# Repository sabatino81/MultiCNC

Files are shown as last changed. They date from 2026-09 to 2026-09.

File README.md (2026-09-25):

# MultiCNC

MultiCNC is a modular, high-precision desktop CNC platform.

This repository is the engineering source of truth for the project: business case, architecture, BOMs, modules, interfaces, decisions and technical documentation.

## Documentation
Open `index.html` for the navigable engineering dashboard (works from disk, any web root or GitHub Pages subpath).

## Current design principles
- Three bases (Light Core ~18 kg, Standard ~45 kg (mule v2, soglia 42 kg, target 35–37 kg), Pro ~70 kg) sharing work area, pallets, kinematics and the **common mechanical interface** of the ToolDock (ICD v4).
- Two electrical profiles (ICD v4, D026): **Core** on the Light Core (grblHAL, open-loop, manual ToolDock clamp) and **Platform** on Standard and Pro (Mesa + LinuxCNC, closed-loop, automatic ToolDock, data bus).
- The **Platform Pack** is a field upgrade that brings the Light Core to the Platform profile, reusing motors, mechanics and cabling (D026).
- Automatic ToolDock for complete head/module changes on the Platform profile; same master, receiver and pull-stud on every base.
- ATC is separate from ToolDock: ATC changes cutters inside an ATC spindle; ToolDock changes the complete process module.
- Optional enclosure on every base, as an independent skin fixed to the base frame, never to the gantry (D025).
- Modular expansion rather than a fully-loaded base: PCB, aluminium, thermoforming, diode laser, fiber MOPA, knife, dispenser and vision are modular capabilities.
- Specifications marked **TARGET** are engineering goals until validated on hardware. Light Core and Platform Pack BOMs are volume-50 cost targets; Standard and Pro BOMs are single-unit prototype estimates.

## Status
V0.6 — Business chapter, Light Core / Platform Pack, ICD v4, optional enclosure; Standard in development — 25 Sep 2026.

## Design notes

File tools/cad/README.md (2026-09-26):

# CAD parametrico MultiCNC

`parts.py` definisce in CadQuery i componenti commerciali ricorrenti (rotaie e pattini HIWIN, viti SFU con chiocciola, motori NEMA17/23 closed-loop). `build_step.py` li esporta in `cad/step/` insieme a `manifest.json`.

## Digital mule della Standard

- `standard_params.py`: unica fonte di verità geometrica della Standard (corse, componenti, catena di quote, parametri MULE).
- `standard_assembly.py`: costruisce l'assieme in HOME, CENTER, MAX e DOCK (D027), controlla collisioni, giochi e margini di fine corsa, calcola ingombri e masse, verifica D015 con i bracci reali; scrive `cad/standard/standard_mule_<config>.step`, `cad/standard/report.json` e la pagina `base/cad-standard.html` (generata: non modificarla a mano).
- `render_views.py`: viste ortografiche di controllo in `cad/standard/views/` (richiede Pillow).
- `standard_detail.py`: lavorazioni di dettaglio dei pezzi custom (fori di guide, pattini, supporti, chiocciole, motori, interfaccia spalla ICD v4 §5, ToolDock con clamp, porte e connettori) ricavate dalle posizioni reali dei componenti; aggiunge le piastre ponte dei BK/BF Z e compila la viteria. Lo applica `standard_assembly.build()` (`DETAIL = True`); le FEA lo spengono.
- `standard_parts.py`: uno STEP per pezzo custom (coordinate locali) e uno per riga BOM (coordinate HOME) in `cad/standard/parts/`, viste, `manifest.json` (letto dalle BOM) e la pagina `base/cad-parts.html` (generata).
- `standard_accessories.py`: rialzi spalle MC-RS-001 (dettaglio), magazine + trasferitore MC-TD-006 (layout), cabina MC-ENC-001.

```sh
python3 -m venv .venv && .venv/bin/pip install cadquery pillow   # una volta
.venv/bin/python tools/cad/build_step.py                  # rigenera gli STEP dei componenti
.venv/bin/python tools/cad/standard_assembly.py           # assieme, report e pagina
.venv/bin/python tools/cad/render_views.py                # viste
.venv/bin/python tools/cad/standard_parts.py              # STEP e viste dei pezzi di dettaglio, pagina pezzi
python3 tools/bom/build.py                                 # aggiorna i link nelle BOM
```

La mappa riga BOM → file STEP è `OWN` in `tools/bom/cad_sources.py`.

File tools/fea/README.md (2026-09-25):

# FEA a solidi · D031

Pipeline lineare statica per i pezzi del mule Standard: solidi CadQuery dal CAD del mule → mesh Gmsh (tetra
quadratici C3D10, ottimizzati high-order) → `.inp` CalculiX → spostamenti dei punti di riferimento e tensioni nodali.

- `ccx.py`: modulo generico (corpi incollati, corpi rigidi, molle SPRING2 anche rotazionali, molle in direzione
  qualsiasi con equazioni, casi di carico, lettura `.dat` / `.frd`, qualità della mesh).
- `d031.py`: fase 1, modello pilota master ToolDock + testa 5045-style; autotest delle molle, mesh nominale e fine,
  varianti; scrive `fea/d031/pilot.json` e rigenera `base/fea-d031.html` (via `d031_page.py`).

## Requisiti

- Python con CadQuery, numpy, scipy e `gmsh` (`pip install gmsh`; su Linux servono anche `libglu1-mesa`,
  `libxcursor1`, `libxinerama1`, `libxft2`).
- CalculiX `ccx` nel PATH (Ubuntu: `apt install calculix-ccx`, solutore SPOOLES). Un `ccx` compilato con PARDISO
  (per esempio quello di PrePoMax su Windows) è molto più veloce sui modelli grandi.

## Uso

```
python tools/fea/d031.py            # completo: ~40 min con 4 core e SPOOLES
python tools/fea/d031.py --quick    # solo autotest, nominale e mesh fine
python tools/fea/d031.py --resume   # riusa nominale e fine da pilot.json, ricalcola autotest e varianti
python tools/fea/d031_page.py       # solo la pagina dal JSON
```

Fase 2a: `python tools/fea/d031_z.py` (testa + master + slitta Z, quattro topologie master ↔ slitta).
Vista 3D: `python tools/fea/export_results.py` (richiede `trimesh`) scrive le deformate colorate in `fea/d031/glb/` per `base/viewer-3d.html`.

File di lavoro in `build/fea/` (non versionati). Regole D031: carichi su punti di riferimento (mai su un nodo),
spostamento relativo naso ER11 ↔ riferimento, convergenza con dimensioni −30% entro il 5% alla punta, tensione
"hotspot" lontano da vincoli, patch rigide ed elementi scadenti; guide, viti e ToolDock come molle calibrate D028.

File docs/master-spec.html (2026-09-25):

← Dashboard

Source of truth

# Master Specification

I valori marcati TARGET sono obiettivi ingegneristici e non specifiche commerciali finché non saranno validati sul prototipo.

## Piattaforma

Parametro | Specifica
Area XY | TARGET 450 × 350 mm
Z CNC | TARGET 120–140 mm
Line-up | Tre basi: Light / Standard / Pro (D007); in sviluppo la Standard
Massa meccanica | TARGET ~18 / ~32 / ~70 kg, quadro elettrico esterno
Clearance | Rialzi manuali (Light, Standard); TARGET 0–150 mm Gantry Lift motorizzato (Pro)
Load case | D014: forze, momenti, accelerazioni, crash e rigidezza alla punta per base
Interfacce comuni | Congelate in ICD v4 (D012): ToolDock, connettore, Module ID, pallet, rialzi, quadro
Carico ToolDock | TARGET 2 / 4 / 7 kg testa completa
Motion | Ponte fisso + tavola mobile Y con vite centrale (D006); guide lineari + viti a ricircolo; closed-loop su Standard e Pro; open-loop sulla Light Core, closed-loop con Platform Pack (D024)
Ingombro Y | TARGET ~750–800 mm, corsa Y + lunghezza tavola, da confermare in CAD
Controller | Standard e Pro: Mesa 7i96S + LinuxCNC + espansione I/O (ICD v4), modello scheda da confermare. Light Core: grblHAL 32 bit con driver integrati; Mesa + LinuxCNC con il Platform Pack (D024, D026)
Altezza pezzo | Non coincide con la corsa Z (140 mm): sotto la trave ci sono 150 mm sopra la tavola, meno pallet e fixture (con pallet 15 mm ~135 mm), +75 mm con i rialzi (D007, D028). Nelle specifiche si dichiarano separatamente
Cabina | Opzionale su tutte le basi (D025): telaio indipendente agganciato al basamento, mai al ponte; porta con interlock, LED, aspirazione Ø100, vasca trucioli; i kit laser richiedono una variante laser-ready o una schermatura propria, qualificate per il modulo specifico (lunghezza d'onda, protezione ottica, interlock, fughe)

## Regole architetturali

Ogni base deve funzionare autonomamente come router CNC; Interfaccia meccanica ToolDock, pallet e cinematica sono comuni alle tre; elettronica e ToolDock automatico sono comuni a Standard e Pro, la Light Core li riceve con il Platform Pack (D024). Thermoforming, PCB specialistico, Aluminium Pro, diode, fiber, knife, dispenser e vision sono moduli.

## Precisione

Accuratezza e ripetibilità restano target finché non definiamo metrologia, condizioni termiche e protocollo di test sul prototipo.

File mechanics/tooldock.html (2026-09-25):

← Dashboard

Universal interface

# Automatic ToolDock

Interfaccia universale tra carrello Z e moduli di processo, progettata per deposito e prelievo automatico della testa.

## Requisiti congelati

- Un solo master ToolDock sulla macchina.
- Ogni testa possiede una receiver plate compatibile.
- Cambio automatico completo: deposito, sgancio, prelievo, aggancio e identificazione.
- Connessioni per potenza, segnali/dati e, dove richiesto, aria o fluido.
- Offset specifici del modulo memorizzati dal controllo.
- Rack raggiungibile cinematicamente dalla macchina.

## ToolDock vs ATC

ToolDock cambia una tecnologia completa. Un modulo spindle ISO20 ATC può successivamente cambiare le proprie frese usando un rack ATC separato.

Congelato in ICD v4 (D012): accoppiamento a 3 sfere, clamp a molla con sgancio passivo dal dock, classi di carico 2/4/7 kg e pin-out del connettore. Restano TARGET la ripetibilità (≤ 10 µm) e il tempo di cambio. Apri la ICD → · Validazione meccanica D016 →

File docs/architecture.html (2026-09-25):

← Dashboard

System architecture

# One machine. Multiple processes.

## XYZ Precision Motion

È la cinematica di lavorazione: X e Z sul ponte fisso, Y come tavola mobile con vite centrale (D006). Deve restare indipendente dal meccanismo di regolazione altezza gantry.

## Clearance · Gantry Lift G

Light e Standard: rialzi manuali spinati. Pro: due punti di sollevamento sincronizzati. Serve per cambiare clearance; durante il taglio il carico si chiude su riferimenti/blocchi meccanici, non sul motore di lift.

## Automatic ToolDock

Cambia l'intero modulo di processo: spindle base, micro-spindle PCB, laser, knife, dispenser, vision/probe e futuri moduli. Automatico su Standard e Pro; sulla Light Core la stessa interfaccia è a bloccaggio manuale finché non monta il Platform Pack (D024).

## ATC ≠ ToolDock

Un futuro spindle ISO20 ATC cambia le proprie frese. ToolDock cambia invece l'intera testa ISO20 con un'altra tecnologia.

## Interchangeable Pallets

Piano CNC, vacuum PCB, thermoforming plenum, laser honeycomb e fixture speciali condividono riferimenti geometrici definiti.

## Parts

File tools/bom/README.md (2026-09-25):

# BOM generator

Le tabelle delle quattro BOM (tre basi e Platform Pack) sono generate da dati Python, non scritte a mano. Standard e Pro: stime di prototipo a pezzo singolo. Light Core e Platform Pack: costi TARGET a lotto da 50 (D023).

| Base | Dati | Pagina |
|---|---|---|
| Light Core | `data_light.py` | `bom/base-light.html` (prezzi TARGET a lotto da 50, D024) |
| Standard | `data_standard.py` | `bom/base.html` |
| Pro | `data_pro.py` | `bom/base-pro.html` |
| Platform Pack | `data_platform.py` | `bom/platform-pack.html` (upgrade Light Core, prezzi TARGET a lotto da 50, D026) |

## Uso

Dalla radice del repository:

```sh
python3 tools/bom/build.py          # riscrive righe, KPI e totali nelle tre pagine
python3 tools/bom/build.py --check  # verifica soltanto; exit 1 se una pagina non è allineata
```

Lo script stampa per ogni base righe, costo prototipo, massa sulla macchina, massa esterna e massa per gruppo.

## Formato di una riga

```python
("MC-TD-001", "ToolDock", "Master kinematic plate", "1", 1,
 "Custom 3-point kinematic interface", "Montata sul carrello Z",
 150, 0.6, "M", "critical", "CRITICAL DESIGN")
```

id · gruppo · componente · quantità (etichetta) · quantità (numero) · candidate · specifica · €/cad · kg/cad · dove · classe stato · stato

- **dove**: `M` sulla macchina, `C` nel quadro o in unità esterne, `A` accessorio (elencato ma escluso dai totali).
- **classe stato**: `design`, `source`, `validate`, `critical`, `ok` (colore della pillola).
- **Codici**: `MC-` parti comuni alle tre basi, `ML-` solo Light, `MP-` solo Pro; le parti della sola Standard usano ancora `MC-`.

## Colonna CAD / STEP

`cad_sources.py` decide cosa mostrare per ogni id:

- `BY_ID` → link alla pagina ufficiale del produttore (`VENDOR`), verificato a mano;
- id di parti custom (`CUSTOM`) → "MultiCNC CAD · in arrivo";
- tutto il resto → "Generico · STEP dal fornitore scelto".

I file dei produttori non vanno copiati nel repository: le loro condizioni d'uso di solito ne vietano la ripubblicazione.

## Cosa non fa

Aggiorna solo tabella, i 4 KPI e la riga "Stima ingegneristica attuale". Testi, callout, target e pannelli restano nell'HTML: se un cambio di dati li rende falsi (per esempio una massa citata nel callout), vanno corretti a mano insieme alle altre pagine che citano quei numeri.

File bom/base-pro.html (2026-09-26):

ID | Gruppo | Componente | Q.tà | Candidate / Part | Specifica tecnica | €/cad target | Subtotale | Massa kg | Stato | CAD / STEP
A · Struttura e riferimenti
MP-BAS-001 | Structure | Basamento lavorato | 1 | Scala in tubi Al 80×60 sp. 4, senza fondo, saldata e lavorata | Longheroni, traversa BF, traversa BK Y e traversa di coda; 4 sbalzi 80×60 sotto le flange ICD §5 dei montanti del lift, niente traversa anteriore (CAD v2, D037) | €250 | €250 | 8.6 macchina | CAD v1 | STEP pezzo ↓CAD di dettaglio
MP-GAN-001 | Structure | Trave gantry | 1 | Scatolato Al 100×170, faccia guide 8, pareti 4, testate 5 | Ponte fisso (D006), canale vite X, staffe del Gantry Lift sul retro (CAD v2, D037) | €160 | €160 | 5.8 macchina | CAD v1 | STEP pezzo ↓CAD di dettaglio
MP-GAN-002 | Structure | Spalle gantry | 2 | Custom Al 12 mm finestrato + traversa superiore 12 × 30 | Montanti del Gantry Lift dietro la trave, 4 finestre ai lati della guida, flangia ICD §5 12 mm scaricata; portano guide, viti, cinghia e motore G (CAD v2, D037) | €60 | €120 | 4.6 macchina | CAD v1 | STEP pezzo ↓CAD di dettaglio
MP-Z-001 | Structure | Piastra asse Z | 1 | Custom Al 5083 12 mm, ali 10 | Guide Z + ToolDock master (CAD v2, D037) | €80 | €80 | 1.1 macchina | CAD v1 | STEP pezzo ↓CAD di dettaglio
MP-XC-001 | Structure | Carrello X | 1 | Al 12 mm, piastra + torre + ali 10 | Porta pattini X, guide Z, vite, supporti e motore Z (CAD v2, D037) | €120 | €120 | 4.4 macchina | CAD v1 | STEP pezzo ↓CAD di dettaglio
MP-BRK-001 | Structure | Staffe chiocciole, motori e supporti | 1 set | Custom Al, 7 pezzi | Staffe chiocciola X e Y, piastrina chiocciola Z, staffa motore Z, spessori BK/BF X, piastre ponte BK/BF Z (CAD di dettaglio v1, D035) | €45 | €45 | 0.9 macchina | CAD v1 | STEP pezzo ↓CAD di dettaglio
MP-TBL-001 | Workholding | Tavola Y / tooling plate | 1 | Al tooling plate 12 mm | Tavola mobile Y (D006), 450×350 utile; spessore pieno, inserti M6 per usura (D018) | €120 | €120 | 5.0 macchina | CAD v1 | STEP pezzo ↓CAD di dettaglio
MP-HW-001 | Structure | Fasteners + dowel pins | 1 set | ISO high-strength | Viteria, spine rettificate, rondelle, inserti | €50 | €50 | 1.0 macchina | TO SOURCE | GenericoSTEP dal fornitore scelto
MC-TBL-002 | Workholding | Inserti M6 + boccole R1/R2 | 1 set | 63 inserti filettati M6 in acciaio + 2 boccole Ø8 H7 | Filetto utile 9 mm nei boss; R1 (50, 50) tonda, R2 (400, 50) asola (ICD v4, D018) | €25 | €25 | 0.1 macchina | TO SOURCE | GenericoSTEP dal fornitore scelto
B · Cinematica XYZ
MP-LIN-201 | XY | Guide lineari HGR20 | 4 rails | HIWIN HGR20 class | 2 rail Y nel basamento + 2 rail X sulla trave, 650 mm (D019) | €60 | €240 | 5.8 macchina | TO SOURCE | STEP MultiCNC ↓modello a quote realiHIWIN CAD ↗ (https://www.hiwinsupport.com/cad_download/linear_guideway.aspx)account gratuito
MP-LIN-202 | XY | Pattini HGH20CA | 8 | HIWIN HGH20CA class | 2 pattini per rail; preload TBC | €20 | €160 | 2.4 macchina | TO SOURCE | STEP MultiCNC ↓modello a quote realiHIWIN CAD ↗ (https://www.hiwinsupport.com/cad_download/linear_guideway.aspx)account gratuito
MP-LIN-151 | Z | Guide lineari HGR15 | 2 rails | HIWIN HGR15 class | 320 mm (D019), corsa Z 120–140 mm | €32 | €64 | 0.9 macchina | TO SOURCE | STEP MultiCNC ↓modello a quote realiHIWIN CAD ↗ (https://www.hiwinsupport.com/cad_download/linear_guideway.aspx)account gratuito
MP-LIN-152 | Z | Pattini HGH15CA | 4 | HIWIN HGH15CA class | 4 pattini complessivi | €15 | €60 | 0.7 macchina | TO SOURCE | STEP MultiCNC ↓modello a quote realiHIWIN CAD ↗ (https://www.hiwinsupport.com/cad_download/linear_guideway.aspx)account gratuito
MP-BS-1605X | X | Ball screw X | 1 | SFU1605 C7 precaricata | 590 mm totali (D019); precarico/errore passo da qualificare. Massa dal CAD: vite piena Ø16 + chiocciola (limite superiore) | €55 | €55 | 1.1 macchina | TO VALIDATE | STEP MultiCNC ↓modello a quote reali
MP-BS-1605Y | Y | Ball screw Y | 1 | SFU1605 C7 precaricata | Vite singola centrale sotto la tavola (D006), 490 mm totali (D019). Massa dal CAD (limite superiore) | €55 | €55 | 1.0 macchina | TO VALIDATE | STEP MultiCNC ↓modello a quote reali
MP-BS-1204Z | Z | Ball screw Z | 1 | SFU1204 C7 | 260 mm totali (D019). Massa dal CAD (limite superiore) | €45 | €45 | 0.3 macchina | TO VALIDATE | STEP MultiCNC ↓modello a quote reali
MP-BKBF-001 | XYZ | Supporti BK/BF precision | 3 set | BK/BF matched class | Supporti cuscinetto per le tre viti | €25 | €75 | 1.8 macchina | TO SOURCE | GenericoSTEP dal fornitore scelto
MP-CPL-001 | XYZ | Giunti motore-vite | 3 | Zero/low backlash bellows class | Da evitare giunti elicoidali economici | €15 | €45 | 0.4 macchina | TO SOURCE | GenericoSTEP dal fornitore scelto
MP-MOT-001 | XYZ | Motori NEMA23 closed-loop 3 Nm | 3 | StepperOnline 3 Nm class | Motore + encoder sulla macchina | €43 | €129 | 4.5 macchina | CANDIDATE | STEP MultiCNC ↓modello a quote realiStepperOnline ↗ (https://www.omc-stepperonline.com/nema-23-closed-loop-stepper-motor-3-0nm-424oz-in-encoder-1000ppr-4000cpr-23hs45-4204d-e1000)23HS45-4204D-E1000
MP-DRV-001 | XYZ | Driver closed-loop | 3 | CL57T class, ~48 V | Nel quadro esterno | €22 | €66 | 1.0 esterno | CANDIDATE | StepperOnline ↗ (https://www.omc-stepperonline.com/closed-loop-stepper-kit)kit closed-loop
C · Gantry Lift motorizzato (solo Pro)
MP-GL-LIN1 | Gantry Lift | Guide verticali HGR15 | 2 rails | HIWIN HGR15 class | Una guida per montante, 350 mm (verificata D019) | €30 | €60 | 1.0 macchina | TO DESIGN | STEP MultiCNC ↓modello a quote realiHIWIN CAD ↗ (https://www.hiwinsupport.com/cad_download/linear_guideway.aspx)account gratuito
MP-GL-LIN2 | Gantry Lift | Pattini HGH15 | 4 | HIWIN HGH15 class | 2 pattini per lato | €15 | €60 | 0.7 macchina | TO DESIGN | STEP MultiCNC ↓modello a quote realiHIWIN CAD ↗ (https://www.hiwinsupport.com/cad_download/linear_guideway.aspx)account gratuito
MP-GL-BS | Gantry Lift | Viti sollevamento | 2 | SFU1605 class | Sollevamento sincronizzato, non asse di taglio; 350 mm totali. Massa dal CAD (limite superiore) | €40 | €80 | 1.5 macchina | TO DESIGN | STEP MultiCNC ↓modello a quote reali
MP-GL-BK | Gantry Lift | Supporti BK/BF lift | 2 set | BK/BF12 class | Supporto viti lift | €20 | €40 | 1.0 macchina | TO SOURCE | GenericoSTEP dal fornitore scelto
MP-GL-MOT | Gantry Lift | Motore G | 1 | NEMA23 closed-loop class | Asse di setup, non richiede precisione metrologica | €43 | €43 | 1.5 macchina | CANDIDATE | STEP MultiCNC ↓modello a quote realiStepperOnline ↗ (https://www.omc-stepperonline.com/nema-23-closed-loop-stepper-motor)NEMA23 closed-loop
MP-GL-DRV | Gantry Lift | Driver G | 1 | CL57T class | Nel quadro esterno | €22 | €22 | 0.3 esterno | CANDIDATE | StepperOnline ↗ (https://www.omc-stepperonline.com/closed-loop-stepper-kit)kit closed-loop
MP-GL-SYNC | Gantry Lift | Sincronizzazione | 1 set | HTD belt + pulleys + shaft | Sincronizza le due viti verticali; massa dal CAD (pulegge piene, cinghia, giunto) | €50 | €50 | 0.9 macchina | TO DESIGN | GenericoSTEP dal fornitore scelto
MP-GL-LOCK | Gantry Lift | Locking + references | 1 set | Custom clamp / wedge / dowel | Scarica il lift durante la lavorazione; staffe trave a C (D037) | €100 | €100 | 2.0 macchina | CRITICAL DESIGN | STEP pezzo ↓CAD di dettaglio
D · Spindle base
MP-SP-001 | Spindle | Spindle 1.5 kW ER16 | 1 | Water-cooled 80 mm class | ~24k rpm; runout da bench-test; testa entro il carico ToolDock di 7 kg | €160 | €160 | 4.5 macchina | TO QUALIFY | GenericoSTEP dal fornitore scelto
MP-SP-002 | Spindle | VFD vector | 1 | 1.5 kW class | RS485/analog; nel quadro esterno | €120 | €120 | 1.5 esterno | TO SOURCE | GenericoSTEP dal fornitore scelto
MC-SP-006 | Spindle | Contattore uscita spindle | 1 | Contattore AC-3 con contatto ausiliario | Apre P1–P3 a valle di VFD/driver prima dello sgancio della testa (ICD v4, D020) | €25 | €25 | 0.2 esterno | TO DESIGN | GenericoSTEP dal fornitore scelto
MP-SP-003 | Spindle | Spindle mount | 1 | Custom machined clamp | Receiver-compatible con ToolDock | €40 | €40 | 1.1 macchina | CAD v1 | STEP pezzo ↓CAD di dettaglio
MP-SP-004 | Cooling | Cooling loop | 1 | Pump + radiator + reservoir | Unità esterna a circuito chiuso | €60 | €60 | 2.5 esterno | TO SOURCE | GenericoSTEP dal fornitore scelto
MP-SP-005 | Tooling | ER16 collet starter set | 1 | Precision collets class | Starter tooling only | €30 | €30 | 0.3 macchina | TO SOURCE | GenericoSTEP dal fornitore scelto
E · ToolDock (identico sulle tre basi)
MC-TD-001 | ToolDock | Master kinematic plate | 1 | Stessa parte della Standard | Montata sul carrello Z | €150 | €150 | 1.0 macchina | CRITICAL DESIGN | STEP pezzo ↓CAD di dettaglio
MC-TD-002 | ToolDock | Base spindle receiver | 1 | Receiver ICD comune, 110 × 110 per il mount Ø80 | Stesso accoppiamento, pull-stud e porte della Standard; più largo (110, limite ICD) per le viti del mount dello spindle Ø80 (CAD v1) | €80 | €80 | 0.5 macchina | CAD v1 | STEP pezzo ↓CAD di dettaglio
MC-TD-003 | ToolDock | Automatic clamp | 1 | Pull-stud comune (ICD v4) | Pacco molle ≥ 3,8 kN (classe P), sgancio passivo con camma 3:1 (D016) | €100 | €100 | 0.4 macchina | CRITICAL DESIGN | STEP pezzo ↓CAD di dettaglio
MC-TD-004 | ToolDock | Hybrid connector set | 1 | Stessa parte della Standard | Power + signal + ID | €120 | €120 | 0.3 macchina | CRITICAL DESIGN | GenericoSTEP dal fornitore scelto
MC-TD-005 | ToolDock | Module ID | 1 | Stessa parte della Standard | Identificazione automatica | €30 | €30 | 0.0 macchina | TO DESIGN | GenericoSTEP dal fornitore scelto
MC-TD-007 | ToolDock | Connettore dati | 1 | Blind-mate a contatti a molla, schermato | Ethernet 1000BASE-T (4 coppie) + CAN FD + encoder RS-422 differenziale (ICD v4, D020) | €60 | €60 | 0.1 macchina | TO SOURCE | GenericoSTEP dal fornitore scelto
F · Controllo (quadro esterno)
MC-CTRL-001 | Control | Motion controller | 1 | Mesa 7i96S | Comune alle tre basi; I/O da verificare con il lift | €160 | €160 | 0.2 esterno | I/O REVIEW | Mesa ↗ (http://www.mesanet.com/)nessuno STEP ufficiale
MC-CTRL-003 | Control | Espansione I/O | 1 | Scheda Mesa su porta di espansione 7i96S (modello da confermare) | ≥ +16 ingressi / +8 uscite 24 V: home, probe, setter, conferme ToolDock, sensori testa, interlock (ICD v4) | €90 | €90 | 0.2 esterno | I/O REVIEW | GenericoSTEP dal fornitore scelto
MC-CTRL-004 | Control | Interfaccia CAN FD | 1 | Adattatore USB–CAN FD | Bus moduli ToolDock (ICD v4, D020) | €40 | €40 | 0.1 esterno | TO SOURCE | GenericoSTEP dal fornitore scelto
MC-CTRL-002 | Compute | Fanless mini PC | 1 | x86 LinuxCNC, 2 porte Ethernet | Porta 1 dedicata alla Mesa, porta 2 per il bus dati ToolDock (D017) | €150 | €150 | 0.8 esterno | TO SOURCE | GenericoSTEP dal fornitore scelto
MP-PWR-001 | Power | 48 V PSU | 1 | Mean Well LRS-600-48 | Motion supply, 4 assi | €70 | €70 | 1.3 esterno | TO SOURCE | Mean Well ↗ (https://www.meanwell.com/webapp/product/search.aspx?prod=LRS-600)LRS-600
MC-PWR-002 | Power | 24 V PSU | 1 | Mean Well HDR-100-24 | ~92 W (24 V × 3,83 A): I/O, sensori, logica ToolDock; 40 W garantiti ai moduli (ICD v4, D022) | €45 | €45 | 0.3 esterno | TO SOURCE | Mean Well ↗ (https://www.meanwell.com/webapp/product/search.aspx?prod=HDR-100)HDR-100
MP-PWR-003 | Power | 48 V MODULE AUX | 1 | Mean Well LRS-350-48 | Linea 48 V dedicata ai moduli ToolDock, separata dal motion (ICD v4, D020) | €60 | €60 | 0.8 esterno | TO SOURCE | Mean Well ↗ (https://www.meanwell.com/webapp/product/search.aspx?prod=LRS-350)LRS-350
MC-SAFE-001 | Safety | E-stop + contactor chain | 1 set | Industrial safety hardware | Arresto energia motion/process | €80 | €80 | 0.5 esterno | TO DESIGN | GenericoSTEP dal fornitore scelto
MP-IO-001 | I/O | Relays / terminal blocks / protection | 1 set | DIN rail industrial | Fusibili, interruttori, relè, morsetti | €90 | €90 | 0.8 esterno | TO SOURCE | GenericoSTEP dal fornitore scelto
MP-EL-BOX | Electrical | Quadro elettrico esterno | 1 | DIN cabinet | Controller, PSU, driver, VFD separato | €80 | €80 | 3.0 esterno | TO DESIGN | GenericoSTEP dal fornitore scelto
G · Cablaggio, sensori e metrologia
MP-CAB-001 | Electrical | Cavi schermati macchina–quadro | 1 set | Motion + spindle + I/O | EMC-aware routing, 4 assi | €100 | €100 | 1.2 macchina | TO SOURCE | GenericoSTEP dal fornitore scelto
MP-CHAIN-001 | Mechanical | Drag chains | 1 set | Low-profile cable chain | X/Z sul ponte + escursione lift | €50 | €50 | 0.6 macchina | TO SOURCE | GenericoSTEP dal fornitore scelto
MC-SNS-001 | Sensing | Home/limit sensors | 6 | Inductive industrial class | XYZ + gantry lift reference | €8 | €48 | 0.3 macchina | TO SOURCE | GenericoSTEP dal fornitore scelto
MC-PROBE-001 | Metrology | XYZ touch probe | 1 | Wired probe class | Work offset / edge finding | €45 | €45 | 0.2 macchina | TO QUALIFY | GenericoSTEP dal fornitore scelto
MC-TOOL-001 | Metrology | Tool length setter | 1 | Wired setter class | Tool length reference | €55 | €55 | 0.3 macchina | TO QUALIFY | GenericoSTEP dal fornitore scelto
H · Accessori (non inclusi nei totali)
MP-ENC-001 | Enclosure | Cabina opzionale Pro | 1 | Telaio indipendente rinforzato + pannelli PC 5 mm + porta con interlock | Più alta per il Gantry Lift e lo spindle ad acqua; agganciata al basamento, mai al ponte; LED, aspirazione Ø100, vasca trucioli e MQL; prezzo TARGET a lotto 50 (D025) | €380 | €380 | 18.0 accessorio | TO DESIGN | STEP pezzo ↓CAD di dettaglio
MC-TD-006 | ToolDock | Magazine indicizzato | 1 | 2–4 posti, indicizzazione motorizzata | Sul ponte; presenta la testa in un'unica posizione di docking; forcelle con sensore di cattura, camma di sgancio 3:1 (D016, D021) | €200 | €200 | 2.0 accessorio | TO DESIGN | STEP pezzo ↓CAD di dettaglio
I · Totali provvisori
Stima ingegneristica attuale (target cost, non RFQ) |  |  |  |  |  |  | €4,557 | 69.6 + 13.6 | PROVISIONAL
Target Base Pro |  |  |  |  |  |  | da definire | ~70 | ACCEPTED

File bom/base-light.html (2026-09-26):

ID | Gruppo | Componente | Q.tà | Candidate / Part | Specifica tecnica | €/cad target | Subtotale | Massa kg | Stato | CAD / STEP
A · Struttura e riferimenti
ML-BAS-001 | Structure | Telaio basamento | 1 | Tubi Al 40×40×1,5 saldati a scala, pad e sedi lavorati in lotto | Due longheroni, traversa BF, traversa di coda 40×80 (BK Y + motore Y), 4 sbalzi 40×40 sotto le flange ICD §5 delle spalle; niente traversa anteriore (CAD v2, D036) | €80 | €80 | 1.8 macchina | CAD v1 | STEP pezzo ↓CAD di dettaglio
ML-GAN-001 | Structure | Trave gantry | 1 | Tubo Al 40×80, faccia guide 4 mm, pareti 2 mm, lavorato in lotto | Ponte fisso (D006), senza canale: guide X MGN12 a 52 mm sulla faccia, vite X e BK10/BF10 sul cielo; blocchetti d'angolo per le M6 delle spalle (CAD v2, D036) | €35 | €35 | 1.2 macchina | CAD v1 | STEP pezzo ↓CAD di dettaglio
ML-GAN-002 | Structure | Spalle gantry | 2 | Al 5083 4 mm + flangia 10 mm scaricata, taglio + lavorazione in lotto | Ai lati della trave, flangia ICD §5 spinata al telaio (pattern invariato, rialzi +50, D007); motore X sulla spalla destra all'altezza della vite (CAD v2, D036) | €15 | €30 | 0.7 macchina | CAD v1 | STEP pezzo ↓CAD di dettaglio
ML-Z-001 | Structure | Piastra asse Z | 1 | Al 5083 6 mm con ali 5 mm | Guide Z + master ToolDock (CAD v2, D036) | €18 | €18 | 0.3 macchina | CAD v1 | STEP pezzo ↓CAD di dettaglio
ML-XC-001 | Structure | Carrello X | 1 | Al 6 mm, piastra + torre, senza ali | Porta pattini X, guide Z a 90 mm, vite, BK Z e motore Z; sopra i pattini X si stringe a 110 mm (CAD v2, D036) | €22 | €22 | 0.5 macchina | CAD v1 | STEP pezzo ↓CAD di dettaglio
ML-BRK-001 | Structure | Staffe chiocciole, motori e supporti | 1 set | Custom Al, 6 pezzi | Staffa chiocciola X sopra la trave, staffa chiocciola Y, piastrina chiocciola Z, staffa motore Z, spessori BK/BF X sul cielo trave, piastra ponte BK Z (CAD v2, D036) | €8 | €8 | 0.5 macchina | CAD v1 | STEP pezzo ↓CAD di dettaglio
ML-TBL-001 | Workholding | Tavola Y / tooling plate | 1 | Al 9 mm, tasche e boss pieni | Tavola mobile Y (D006), 450×350 utile; pelle 4 mm, boss Ø16 × 9 mm attorno ai fori M6 e ai riferimenti (D018): stessi pallet delle altre basi | €60 | €60 | 2.2 macchina | CAD v1 | STEP pezzo ↓CAD di dettaglio
ML-HW-001 | Structure | Fasteners + dowel pins | 1 set | ISO | Viteria, spine, inserti | €15 | €15 | 0.4 macchina | TO SOURCE | GenericoSTEP dal fornitore scelto
MC-TBL-002 | Workholding | Inserti M6 + boccole R1/R2 | 1 set | 63 inserti filettati M6 in acciaio + 2 boccole Ø8 H7 | Filetto utile 9 mm nei boss; R1 (50, 50) tonda, R2 (400, 50) asola (ICD v4, D018) | €14 | €14 | 0.1 macchina | TO SOURCE | GenericoSTEP dal fornitore scelto
B · Cinematica XYZ
ML-LIN-151 | XY | Guide lineari MGN12 | 4 rails | MGN12, HIWIN o equivalente qualificato | 2 rail X 620 mm + 2 rail Y 580 mm (passo pattini Y 160, Light a piastre D036) | €18 | €72 | 1.6 macchina | TO SOURCE | STEP MultiCNC ↓modello a quote realiHIWIN CAD ↗ (https://www.hiwinsupport.com/cad_download/linear_guideway.aspx)account gratuito
ML-LIN-152 | XY | Pattini MGN12H | 8 | MGN12H, HIWIN o equivalente qualificato | 2 pattini per rail, versione lunga, precarico Z1: equivalente accettato solo con rigidezza ≥ HIWIN (175 N/µm, D022) | €5 | €40 | 0.4 macchina | TO SOURCE | STEP MultiCNC ↓modello a quote realiHIWIN CAD ↗ (https://www.hiwinsupport.com/cad_download/linear_guideway.aspx)account gratuito
ML-LIN-153 | Z | Guide lineari MGN12 | 2 rails | MGN12, HIWIN o equivalente qualificato | 280 mm (D019) | €9 | €18 | 0.4 macchina | TO SOURCE | STEP MultiCNC ↓modello a quote realiHIWIN CAD ↗ (https://www.hiwinsupport.com/cad_download/linear_guideway.aspx)account gratuito
ML-LIN-154 | Z | Pattini MGN12H | 4 | MGN12H, HIWIN o equivalente qualificato | 4 pattini complessivi | €5 | €20 | 0.2 macchina | TO SOURCE | STEP MultiCNC ↓modello a quote realiHIWIN CAD ↗ (https://www.hiwinsupport.com/cad_download/linear_guideway.aspx)account gratuito
ML-BS-1204X | X | Ball screw X | 1 | SFU1204 C7 rullata | 570 mm totali, estremità BK/BF comprese (D019); sopra la trave (D036). Massa dal CAD: vite piena Ø12 + chiocciola (limite superiore) | €22 | €22 | 0.6 macchina | TO VALIDATE | STEP MultiCNC ↓modello a quote reali
ML-BS-1204Y | Y | Ball screw Y | 1 | SFU1204 C7 rullata | Vite singola centrale sotto la tavola (D006), 480 mm totali (CAD v1: 8 mm fra staffa e BK a fine corsa). Massa dal CAD (limite superiore) | €22 | €22 | 0.5 macchina | TO VALIDATE | STEP MultiCNC ↓modello a quote reali
ML-BS-1204Z | Z | Ball screw Z | 1 | SFU1204 C7 rullata | 260 mm totali (D019), fissa-libera: solo BK10 in alto (D036). Massa dal CAD (limite superiore) | €22 | €22 | 0.3 macchina | TO VALIDATE | STEP MultiCNC ↓modello a quote reali
ML-BKBF-001 | XYZ | Supporti BK10/BF10 | 2 set + 1 BK10 | BK/BF class | Set BK10/BF10 per X (sul cielo della trave) e Y; solo BK10 per la Z fissa-libera (D036) | €23 | €23 | 0.9 macchina | TO SOURCE | GenericoSTEP dal fornitore scelto
ML-CPL-001 | XYZ | Giunti motore-vite | 3 | Low backlash bellows class | Taglia NEMA17 | €5 | €15 | 0.2 macchina | TO SOURCE | GenericoSTEP dal fornitore scelto
ML-MOT-002 | XYZ | Motori NEMA17 encoder-ready | 3 | NEMA17 ~0,6 Nm, doppio albero | Open-loop sulla Core; il Platform Pack aggiunge un encoder a innesto sul secondo albero, i motori restano (D026). Crash load D014 invariato | €14 | €42 | 1.2 macchina | CANDIDATE | GenericoSTEP dal fornitore scelto
C · Spindle base
ML-SP-001 | Spindle | Spindle BLDC 300–500 W | 1 | ER11, air-cooled | Testa completa entro il carico ToolDock di 2 kg | €60 | €60 | 1.0 macchina | TO QUALIFY | GenericoSTEP dal fornitore scelto
ML-SP-002 | Spindle | Driver BLDC + alimentatore | 1 | 0,5 kW class, alimentatore dedicato | Nel quadro; enable dal controller, tolto dal consenso cambio testa | €45 | €45 | 0.8 quadro | TO SOURCE | GenericoSTEP dal fornitore scelto
ML-SP-003 | Spindle | Spindle mount | 1 | Custom machined clamp | Receiver-compatible con ToolDock | €12 | €12 | 0.2 macchina | CAD v1 | STEP pezzo ↓CAD di dettaglio
ML-SP-005 | Tooling | ER11 collet starter set | 1 | 2 pinze (3,175 · 6 mm) | Starter tooling only | €3 | €3 | 0.1 macchina | TO SOURCE | GenericoSTEP dal fornitore scelto
D · ToolDock manuale (interfaccia ICD comune)
ML-TD-001 | ToolDock | Master kinematic plate | 1 | Stesso accoppiamento a 3 sfere e pull-stud delle altre basi | Montata sul carrello Z; sedi già lavorate per clamp automatico, connettore ibrido e connettore dati del Platform Pack | €60 | €60 | 0.4 macchina | CRITICAL DESIGN | STEP pezzo ↓CAD di dettaglio
ML-TD-002 | ToolDock | Base spindle receiver | 1 | Receiver ICD comune | Stessa receiver delle altre basi: le teste restano intercambiabili | €30 | €30 | 0.3 macchina | CAD v1 | STEP pezzo ↓CAD di dettaglio
ML-TD-003 | ToolDock | Clamp manuale | 1 | Leva a camma sul pull-stud comune | Preload ≥ 0,5 kN come la classe L (D016); sostituito dal clamp automatico nel Platform Pack, che si monta nelle stesse sedi | €35 | €35 | 0.2 macchina | CRITICAL DESIGN | STEP pezzo ↓CAD di dettaglio
ML-TD-004 | ToolDock | Connettore modulo manuale | 1 | Circolare industriale 12 poli | Spindle, 48 V modulo, I/O e ID; si innesta a mano, solo con consenso cambio testa attivo | €15 | €15 | 0.1 macchina | TO SOURCE | GenericoSTEP dal fornitore scelto
MC-TD-005 | ToolDock | Module ID | 1 | 1-Wire comune | Stesso ID delle altre basi: il controller rifiuta le teste non Core-ready | €3 | €3 | 0.0 macchina | TO DESIGN | GenericoSTEP dal fornitore scelto
E · Controllo (quadro esterno)
ML-CTRL-001 | Control | Controller grblHAL | 1 | 32 bit, Ethernet, 3 driver TMC5160 integrati | Al posto di Mesa + PC + driver separati; web UI, niente PC dedicato | €65 | €65 | 0.2 quadro | TO VALIDATE | GenericoSTEP dal fornitore scelto
ML-PWR-001 | Power | 48 V PSU | 1 | Mean Well LRS-200-48 | Motion NEMA17 + linea modulo Core-ready (≤ 60 W) | €28 | €28 | 0.6 quadro | TO SOURCE | Mean Well ↗ (https://www.meanwell.com/webapp/product/search.aspx?prod=LRS-200)LRS-200
ML-EL-BOX | Electrical | Quadro compatto + E-stop | 1 | Box, E-stop, fusibili, morsetti | E-stop su enable driver e spindle; pulsante consenso cambio testa | €27 | €27 | 1.2 quadro | TO DESIGN | GenericoSTEP dal fornitore scelto
F · Cablaggio, sensori e metrologia
ML-CAB-001 | Electrical | Cavi macchina–quadro | 1 set | Cablaggi preassemblati | Motori con poli encoder già previsti, spindle, connettore modulo, sensori: restano con il Platform Pack (D026) | €28 | €28 | 0.6 macchina | TO SOURCE | GenericoSTEP dal fornitore scelto
ML-CHAIN-001 | Mechanical | Drag chains | 1 set | Low-profile cable chain | X/Z sul ponte | €12 | €12 | 0.3 macchina | TO SOURCE | GenericoSTEP dal fornitore scelto
ML-SNS-001 | Sensing | Home sensors | 3 | Micro-switch o induttivi | Home XYZ; i limiti restano sugli hard stop con bumper (D014) | €3 | €9 | 0.1 macchina | TO SOURCE | GenericoSTEP dal fornitore scelto
ML-TOOL-001 | Metrology | Tool length setter | 1 | Wired setter class | Riferimento lunghezza utensile | €12 | €12 | 0.2 macchina | TO QUALIFY | GenericoSTEP dal fornitore scelto
ML-CAB-002 | Electrical | Pressacavi e connettori | 1 set | Pressacavi, capicorda, fascette | Minuteria di cablaggio | €10 | €10 | 0.1 macchina | TO SOURCE | GenericoSTEP dal fornitore scelto
G · Accessori e upgrade (non inclusi nei totali)
ML-UP-001 | Upgrade | Platform Pack | 1 | Upgrade montabile dal cliente, BOM dedicata | Encoder a innesto, driver closed-loop, Mesa + LinuxCNC, clamp automatico, connettori ibrido e dati: profilo Platform della ICD v4 (D026, vedi BOM Platform Pack) | €829 | €829 | 6.4 accessorio | TO DESIGN | GenericoSTEP dal fornitore scelto
ML-PROBE-001 | Metrology | XYZ touch probe | 1 | Wired probe class | Work offset / edge finding | €35 | €35 | 0.2 accessorio | TO QUALIFY | GenericoSTEP dal fornitore scelto
MC-ENC-001 | Enclosure | Cabina opzionale | 1 | Telaio indipendente + pannelli PC 4 mm + porta con interlock | Agganciata al basamento, mai al ponte; LED, attacco aspirazione Ø100, vasca trucioli, fonoassorbente; variante laser-ready da qualificare per ogni modulo laser (lunghezza d'onda, protezione ottica, interlock, verifica delle fughe) (D025) | €280 | €280 | 13.0 accessorio | TO DESIGN | STEP pezzo ↓CAD di dettaglio
ML-RS-001 | Clearance | Rialzi spalle spinati | 1 set | Custom Al blocks +50 mm | Clearance manuale riferita da spine | €30 | €30 | 0.8 accessorio | TO DESIGN | STEP pezzo ↓CAD di dettaglio
MC-TD-006 | ToolDock | Magazine indicizzato | 1 | 2–4 posti, indicizzazione motorizzata | Richiede il Platform Pack; sul ponte, presenta la testa in un'unica posizione di docking (D016, D021) | €200 | €200 | 2.0 accessorio | TO DESIGN | STEP pezzo ↓CAD di dettaglio
H · Totali provvisori
Stima ingegneristica attuale (target cost a lotto 50, non RFQ) |  |  |  |  |  |  | €1,032 | 17.6 + 2.8 | PROVISIONAL
Tetto Light Core (D023) |  |  |  |  |  |  | ≤ €1.050 | ~18 | ACCEPTED

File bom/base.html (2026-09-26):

ID | Gruppo | Componente | Q.tà | Candidate / Part | Specifica tecnica | €/cad target | Subtotale | Massa kg | Stato | CAD / STEP
A · Struttura e riferimenti
MC-BAS-001 | Structure | Telaio a scala | 1 | 2 longheroni Y + 4 traverse, tubi Al 40×60 / 120×60 sp. 3 (D034), saldato e lavorato | Telaio di precisione a scala (D027): longheroni sotto le guide Y con sedi lavorate, traverse fronte / BF / posteriore (porta le spalle) / motore; traversa posteriore estesa sotto il BK Y; massa dal CAD di dettaglio v1 | €180 | €180 | 6.0 macchina | CAD v1 | STEP pezzo ↓CAD di dettaglio
MC-GAN-001 | Structure | Trave gantry | 1 | Custom box Al 80×140, pareti 4 / faccia guide 6 (D034), canale vite | Ponte fisso (D006), interasse guide X 110 mm (D015), centro guide a 246 mm (D027); massa dal CAD di dettaglio v1, da ridisegnare | €150 | €150 | 4.7 macchina | CAD v1 | STEP pezzo ↓CAD di dettaglio
MC-GAN-002 | Structure | Spalle gantry | 2 | Custom Al, scatolate 40 × 120 sp. 4, flangia ICD 12 (D034) | Alte 176 mm sulla traversa posteriore (D027), scatolate (D029, D030); sede rialzi (D007); massa dal CAD di dettaglio v1 | €60 | €120 | 2.0 macchina | CAD v1 | STEP pezzo ↓CAD di dettaglio
MC-Z-001 | Structure | Slitta Z | 1 | Custom Al 12 mm, 150 × 160 a canale con ali anteriori 10 × 35 | Porta i 4 pattini HGH15CA Z e la master ToolDock (D027); ali sopra il piano del coupling (D030); massa dal CAD di dettaglio v1 | €70 | €70 | 0.9 macchina | CAD v1 | STEP pezzo ↓CAD di dettaglio
MC-TBL-001 | Workholding | Tavola Y / tooling plate | 1 | Al tooling plate 10 mm, tasche e boss pieni | Tavola mobile Y (D006), 450×350 utile; pelle 6 mm, boss Ø16 × 10 mm attorno ai fori M6 e ai riferimenti (D018); massa confermata dal mule v1 | €100 | €100 | 3.0 macchina | CAD v1 | STEP pezzo ↓CAD di dettaglio
MC-XC-001 | Structure | Carrello X | 1 | Custom Al 15 mm, 170 × 530 + torre, a canale con ali anteriori 10 × 45 | Porta pattini X, guide Z, vite, supporti e motore Z (D027); ali fuori dalla slitta e dal corridoio di docking (D030); massa dal CAD di dettaglio v1 | €110 | €110 | 3.3 macchina | CAD v1 | STEP pezzo ↓CAD di dettaglio
MC-BRK-001 | Structure | Staffe chiocciole, motori e supporti | 1 set | Custom Al, 7 pezzi | Staffe chiocciola X e Y, piastrina chiocciola Z 16 mm (D031), staffa motore Z, spessori BK/BF X, 2 piastre ponte BK/BF Z (CAD di dettaglio v1); piastre motore X e Y saldate su trave e telaio | €45 | €45 | 0.7 macchina | CAD v1 | STEP pezzo ↓CAD di dettaglio
MC-HW-001 | Structure | Fasteners + dowel pins | 1 set | ISO high-strength | ~311 elementi dalla tabella del CAD di dettaglio (base/cad-parts.html): viti ISO 4762, spine ISO 8734, 63 inserti M6, O-ring, molle a tazza | €40 | €40 | 0.6 macchina | TO SOURCE | GenericoSTEP dal fornitore scelto
MC-TBL-002 | Workholding | Inserti M6 + boccole R1/R2 | 1 set | 63 inserti filettati M6 in acciaio + 2 boccole Ø8 H7 | Filetto utile 9 mm nei boss; R1 (50, 50) tonda, R2 (400, 50) asola (ICD v4, D018) | €25 | €25 | 0.1 macchina | TO SOURCE | GenericoSTEP dal fornitore scelto
B · Cinematica XYZ
MC-LIN-151 | X | Guide lineari HGR15 | 2 rails | HIWIN HGR15 class | Sulla trave, 640 mm (D019), interasse ≥ 110 mm (D015) | €37 | €74 | 1.9 macchina | TO SOURCE | STEP MultiCNC ↓modello a quote realiHIWIN CAD ↗ (https://www.hiwinsupport.com/cad_download/linear_guideway.aspx)account gratuito
MC-LIN-152 | X | Pattini HGH15CA | 4 | HIWIN HGH15CA class | 2 pattini per rail; precarico ZA, 365 N/µm (D015, D022) | €15 | €60 | 0.7 macchina | TO SOURCE | STEP MultiCNC ↓modello a quote realiHIWIN CAD ↗ (https://www.hiwinsupport.com/cad_download/linear_guideway.aspx)account gratuito
MC-LIN-155 | Y | Guide lineari MGN15 | 2 rails | HIWIN MGN15 class | Nel basamento sotto la tavola, 630 mm (D019), interasse ~300 mm (D008, D015) | €32 | €64 | 1.3 macchina | TO SOURCE | STEP MultiCNC ↓modello a quote realiHIWIN CAD ↗ (https://www.hiwinsupport.com/cad_download/linear_guideway.aspx)account gratuito
MC-LIN-156 | Y | Pattini MGN15H | 4 | HIWIN MGN15H class | 2 pattini per rail, versione lunga, precarico Z1 (202 N/µm, D022); 0,09 kg da scheda HIWIN | €12 | €48 | 0.4 macchina | TO SOURCE | STEP MultiCNC ↓modello a quote realiHIWIN CAD ↗ (https://www.hiwinsupport.com/cad_download/linear_guideway.aspx)account gratuito
MC-LIN-153 | Z | Guide lineari HGR15 | 2 rails | HIWIN HGR15 class | 310 mm (D019), corsa Z 120–140 mm | €25 | €50 | 0.9 macchina | TO SOURCE | STEP MultiCNC ↓modello a quote realiHIWIN CAD ↗ (https://www.hiwinsupport.com/cad_download/linear_guideway.aspx)account gratuito
MC-LIN-154 | Z | Pattini HGH15CA | 4 | HIWIN HGH15CA class | 4 pattini complessivi | €15 | €60 | 0.7 macchina | TO SOURCE | STEP MultiCNC ↓modello a quote realiHIWIN CAD ↗ (https://www.hiwinsupport.com/cad_download/linear_guideway.aspx)account gratuito
MC-BS-1605X | X | Ball screw X | 1 | SFU1605 C7 | 590 mm totali, estremità BK/BF comprese (D019); precarico/errore passo da qualificare | €55 | €55 | 1.3 macchina | TO VALIDATE | STEP MultiCNC ↓modello a quote reali
MC-BS-1605Y | Y | Ball screw Y | 1 | SFU1605 C7 | Vite singola centrale sotto la tavola (D006), 490 mm totali (D019) | €55 | €55 | 1.1 macchina | TO VALIDATE | STEP MultiCNC ↓modello a quote reali
MC-BS-1204Z | Z | Ball screw Z | 1 | SFU1204 C7 | 260 mm totali (D019) | €45 | €45 | 0.4 macchina | TO VALIDATE | STEP MultiCNC ↓modello a quote reali
MC-BKBF-001 | XYZ | Supporti BK12/BF12 | 3 set | BK/BF matched class | Supporti cuscinetto per le tre viti | €22 | €66 | 1.5 macchina | TO SOURCE | GenericoSTEP dal fornitore scelto
MC-CPL-001 | XYZ | Giunti motore-vite | 3 | Zero/low backlash bellows class | Da evitare giunti elicoidali economici | €15 | €45 | 0.3 macchina | TO SOURCE | GenericoSTEP dal fornitore scelto
MC-MOT-001 | XYZ | Motori NEMA23 closed-loop ~2 Nm | 3 | StepperOnline 2 Nm class | Motore + encoder sulla macchina | €40 | €120 | 3.6 macchina | CANDIDATE | STEP MultiCNC ↓modello a quote realiStepperOnline ↗ (https://www.omc-stepperonline.com/nema-23-closed-loop-stepper-motor)NEMA23 closed-loop
MC-DRV-001 | XYZ | Driver closed-loop | 3 | CL57T class, ~48 V | Nel quadro esterno | €20 | €60 | 0.9 quadro | CANDIDATE | StepperOnline ↗ (https://www.omc-stepperonline.com/closed-loop-stepper-kit)kit closed-loop
C · Spindle base
MC-SP-001 | Spindle | Spindle HF Ø45 · 650 W S1 | 1 | Riferimento SycoTec 5045 AC-ER11 · 2002 5400; OEM equivalente da qualificare | Ø45 × 180 mm, 1,6 kg, 650 W S1 / 1,28 kW, 6.000–60.000 rpm, 180 V 3,5 A S1, ER11 fino a Ø8, runout ≤ 1,5 µm; raffreddamento dal mount e aria di tenuta 30 l/min (D030). Prezzo = TARGET OEM, non SycoTec | €300 | €300 | 1.6 macchina | TO QUALIFY | GenericoSTEP dal fornitore scelto
MC-SP-002 | Spindle | Inverter HF | 1 | Inverter per spindle asincrono, fino a 1 kHz, 180 V 3~ | Riferimento e@syDrive 4638 / Control Techniques HS30 (catalogo SycoTec); prezzo TARGET OEM; nel quadro esterno | €250 | €250 | 1.2 quadro | TO SOURCE | GenericoSTEP dal fornitore scelto
MC-SP-006 | Spindle | Contattore uscita spindle | 1 | Contattore AC-3 con contatto ausiliario | Apre P1–P3 a valle di VFD/driver prima dello sgancio della testa (ICD v4, D020) | €25 | €25 | 0.2 quadro | TO DESIGN | GenericoSTEP dal fornitore scelto
MC-SP-007 | Spindle | Aria di tenuta spindle | 1 set | Filtro-regolatore, elettrovalvola 24 V, flussostato, raccordi Ø6 | 30 ± 5 l/min sul passaggio Ø6 del ToolDock (ICD v4, D030); aria da rete o compressore esterno, non inclusi; TARGET | €45 | €45 | 0.4 quadro | TO DESIGN | GenericoSTEP dal fornitore scelto
MC-SP-008 | Spindle | Circuito camicia di raffreddamento | 1 set | Pompa 24 V, radiatore con ventola, serbatoio, tubi | Mandata e ritorno sulle 2 porte Ø4 del ToolDock (ICD v4, D030); TARGET | €60 | €60 | 0.9 quadro | TO DESIGN | GenericoSTEP dal fornitore scelto
MC-SP-003 | Spindle | Mount spindle a tazza con camicia | 1 | Custom Al 60 × 60, collare sul Ø45 h6, camicia di raffreddamento | Dal receiver al collare: tazza chiusa con finestra per il connettore M23 a 90° (D030); massa dal CAD di dettaglio v1 | €60 | €60 | 0.5 macchina | CAD v1 | STEP pezzo ↓CAD di dettaglio
MC-SP-005 | Tooling | ER collet starter set | 1 | Precision collets class | Starter tooling only | €25 | €25 | 0.2 macchina | TO SOURCE | GenericoSTEP dal fornitore scelto
D · ToolDock (identico sulle tre basi)
MC-TD-001 | ToolDock | Master kinematic plate | 1 | Custom 3-point kinematic interface, scatolata 120 × 40 sp. 8 con sella a U | Sotto la slitta Z, scatolata (D029, D030); sella a U incollata/bullonata alle ali della slitta (D031, mule v3); massa dal CAD di dettaglio v1 | €150 | €150 | 0.9 macchina | CAD v1 | STEP pezzo ↓CAD di dettaglio
MC-TD-002 | ToolDock | Base spindle receiver | 1 | Custom receiver plate | Receiver della testa spindle Standard, 96 × 96 × 15; massa dal CAD di dettaglio v1 | €80 | €80 | 0.3 macchina | CAD v1 | STEP pezzo ↓CAD di dettaglio
MC-TD-003 | ToolDock | Automatic clamp | 1 | Pull-stud comune (ICD v4) | Pacco molle ≥ 1,6 kN (classe S), sgancio passivo con camma 3:1 (D016) | €100 | €100 | 0.4 macchina | CAD v1 | STEP pezzo ↓CAD di dettaglio
MC-TD-004 | ToolDock | Hybrid connector set | 1 | Power + signal + ID | Quick-connect; pneumatica/fluidi predisposti | €120 | €120 | 0.3 macchina | CRITICAL DESIGN | GenericoSTEP dal fornitore scelto
MC-TD-005 | ToolDock | Module ID | 1 | EEPROM / coded ID | Identificazione automatica del modulo | €30 | €30 | 0.0 macchina | TO DESIGN | GenericoSTEP dal fornitore scelto
MC-TD-007 | ToolDock | Connettore dati | 1 | Blind-mate a contatti a molla, schermato | Ethernet 1000BASE-T (4 coppie) + CAN FD + encoder RS-422 differenziale (ICD v4, D020) | €60 | €60 | 0.1 macchina | TO SOURCE | GenericoSTEP dal fornitore scelto
E · Controllo (quadro esterno)
MC-CTRL-001 | Control | Motion controller | 1 | Mesa 7i96S | Ethernet LinuxCNC motion/I-O baseline, comune alle tre basi | €160 | €160 | 0.2 quadro | I/O REVIEW | Mesa ↗ (http://www.mesanet.com/)nessuno STEP ufficiale
MC-CTRL-003 | Control | Espansione I/O | 1 | Scheda Mesa su porta di espansione 7i96S (modello da confermare) | ≥ +16 ingressi / +8 uscite 24 V: home, probe, setter, conferme ToolDock, sensori testa, interlock (ICD v4) | €90 | €90 | 0.2 quadro | I/O REVIEW | GenericoSTEP dal fornitore scelto
MC-CTRL-004 | Control | Interfaccia CAN FD | 1 | Adattatore USB–CAN FD | Bus moduli ToolDock (ICD v4, D020) | €40 | €40 | 0.1 quadro | TO SOURCE | GenericoSTEP dal fornitore scelto
MC-CTRL-002 | Compute | Fanless mini PC | 1 | x86 LinuxCNC, 2 porte Ethernet | Porta 1 dedicata alla Mesa, porta 2 per il bus dati ToolDock (D017) | €150 | €150 | 0.8 quadro | TO SOURCE | GenericoSTEP dal fornitore scelto
MC-PWR-001 | Power | 48 V PSU | 1 | Mean Well LRS-350-48 | Motion supply | €60 | €60 | 0.9 quadro | TO SOURCE | Mean Well ↗ (https://www.meanwell.com/webapp/product/search.aspx?prod=LRS-350)LRS-350
MC-PWR-002 | Power | 24 V PSU | 1 | Mean Well HDR-100-24 | ~92 W (24 V × 3,83 A): I/O, sensori, logica ToolDock; 40 W garantiti ai moduli (ICD v4, D022) | €45 | €45 | 0.3 quadro | TO SOURCE | Mean Well ↗ (https://www.meanwell.com/webapp/product/search.aspx?prod=HDR-100)HDR-100
MC-PWR-003 | Power | 48 V MODULE AUX | 1 | Mean Well LRS-150-48 | Linea 48 V dedicata ai moduli ToolDock, separata dal motion (ICD v4, D020) | €40 | €40 | 0.6 quadro | TO SOURCE | Mean Well ↗ (https://www.meanwell.com/webapp/product/search.aspx?prod=LRS-150)LRS-150
MC-SAFE-001 | Safety | E-stop + contactor chain | 1 set | Industrial safety hardware | Arresto energia motion/process secondo safety design finale | €80 | €80 | 0.5 quadro | TO DESIGN | GenericoSTEP dal fornitore scelto
MC-IO-001 | I/O | Relays / terminal blocks / protection | 1 set | DIN rail industrial | Fusibili, interruttori, relè, morsetti | €80 | €80 | 0.7 quadro | TO SOURCE | GenericoSTEP dal fornitore scelto
MC-EL-BOX | Electrical | Quadro elettrico esterno | 1 | DIN cabinet | Controller, PSU, driver, VFD; separato dalla macchina | €80 | €80 | 2.5 quadro | TO DESIGN | GenericoSTEP dal fornitore scelto
F · Cablaggio, sensori e metrologia
MC-CAB-001 | Electrical | Cavi schermati macchina–quadro | 1 set | Motion + spindle + I/O | EMC-aware routing | €90 | €90 | 1.0 macchina | TO SOURCE | GenericoSTEP dal fornitore scelto
MC-CHAIN-001 | Mechanical | Drag chains | 1 set | Low-profile cable chain | X/Z sul ponte; Y solo se il cablaggio tavola lo richiede | €45 | €45 | 0.5 macchina | TO SOURCE | GenericoSTEP dal fornitore scelto
MC-SNS-001 | Sensing | Home/limit sensors | 4 | Inductive industrial class | XYZ home + limite | €8 | €32 | 0.2 macchina | TO SOURCE | GenericoSTEP dal fornitore scelto
MC-PROBE-001 | Metrology | XYZ touch probe | 1 | Wired probe class | Work offset / edge finding | €45 | €45 | 0.2 macchina | TO QUALIFY | GenericoSTEP dal fornitore scelto
MC-TOOL-001 | Metrology | Tool length setter | 1 | Wired setter class | Tool length reference | €55 | €55 | 0.3 macchina | TO QUALIFY | GenericoSTEP dal fornitore scelto
G · Accessori (non inclusi nei totali)
MC-ENC-001 | Enclosure | Cabina opzionale | 1 | Telaio indipendente + pannelli PC 4 mm + porta con interlock | Stessa cabina della Light Core; agganciata al basamento, mai al ponte; LED, attacco aspirazione Ø100, vasca trucioli, fonoassorbente; variante laser-ready da qualificare per ogni modulo laser (lunghezza d'onda, protezione ottica, interlock, verifica delle fughe); prezzo TARGET a lotto 50 (D025) | €280 | €280 | 40.8 accessorio | TO DESIGN | STEP pezzo ↓CAD di dettaglio
MC-RS-001 | Clearance | Rialzi spalle spinati | 1 set | Custom Al blocks +75 mm | Clearance manuale riferita da spine (D007); accessorio, non montato di serie (D008) | €60 | €60 | 2.5 accessorio | CAD v1 | STEP pezzo ↓CAD di dettaglio
MC-TD-006 | ToolDock | Magazine indicizzato | 1 | 2–4 posti, indicizzazione motorizzata | Sul ponte; presenta la testa in un'unica posizione di docking; forcelle con sensore di cattura, camma di sgancio 3:1 (D016, D021) | €200 | €200 | 2.0 accessorio | TO DESIGN | STEP pezzo ↓CAD di dettaglio
H · Totali provvisori
Stima ingegneristica attuale (target cost, non RFQ) |  |  |  |  |  |  | €4,039 | 41.7 + 10.4 | PROVISIONAL
Target industrializzato Base Standard |  |  |  |  |  |  | da definire | ~32 | ACCEPTED

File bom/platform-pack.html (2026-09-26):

ID | Gruppo | Componente | Q.tà | Candidate / Part | Specifica tecnica | €/cad target | Subtotale | Massa kg | Stato | CAD / STEP
A · Closed-loop sugli assi
PP-ENC-001 | XYZ | Encoder a innesto | 3 | Encoder magnetico ABZ differenziale 1000 linee | Si monta sul secondo albero dei NEMA17 encoder-ready della Light Core: i motori restano (D026). Da qualificare in coppia con il driver: prova prioritaria | €12 | €36 | 0.2 macchina | TO QUALIFY · COPPIA | GenericoSTEP dal fornitore scelto
PP-DRV-001 | XYZ | Driver closed-loop | 3 | CL42T class, ingresso encoder ABZ | Nel nuovo quadro; deve accettare davvero l'ABZ differenziale di un encoder esterno e chiudere l'anello su un motore non suo: da scegliere insieme all'encoder | €15 | €45 | 0.6 quadro | TO QUALIFY · COPPIA | GenericoSTEP dal fornitore scelto
B · Controllo Mesa + LinuxCNC
MC-CTRL-001 | Control | Motion controller | 1 | Mesa 7i96S | Stesso controller di Standard e Pro | €140 | €140 | 0.2 quadro | I/O REVIEW | Mesa ↗ (http://www.mesanet.com/)nessuno STEP ufficiale
MC-CTRL-003 | Control | Espansione I/O | 1 | Scheda Mesa su porta di espansione 7i96S (modello da confermare) | ≥ +16 ingressi / +8 uscite 24 V (ICD v4, profilo Platform) | €75 | €75 | 0.2 quadro | I/O REVIEW | GenericoSTEP dal fornitore scelto
MC-CTRL-004 | Control | Interfaccia CAN FD | 1 | Adattatore USB–CAN FD | Bus moduli ToolDock | €30 | €30 | 0.1 quadro | TO SOURCE | GenericoSTEP dal fornitore scelto
MC-CTRL-002 | Compute | Fanless mini PC | 1 | x86 LinuxCNC, 2 porte Ethernet | Opzionale se il cliente usa un proprio PC compatibile LinuxCNC (−€120) | €120 | €120 | 0.8 quadro | TO SOURCE | GenericoSTEP dal fornitore scelto
C · Alimentazione e sicurezza
MC-PWR-002 | Power | 24 V PSU | 1 | Mean Well HDR-100-24 | ~92 W: I/O, sensori, logica ToolDock; 40 W garantiti ai moduli (ICD v4) | €35 | €35 | 0.3 quadro | TO SOURCE | Mean Well ↗ (https://www.meanwell.com/webapp/product/search.aspx?prod=HDR-100)HDR-100
MC-PWR-003 | Power | 48 V MODULE AUX | 1 | Mean Well LRS-150-48 | Linea 48 V moduli separata dal motion; il 48 V motion LRS-200-48 della Core resta | €30 | €30 | 0.6 quadro | TO SOURCE | Mean Well ↗ (https://www.meanwell.com/webapp/product/search.aspx?prod=LRS-150)LRS-150
MC-SP-006 | Spindle | Contattore uscita spindle | 1 | Contattore AC-3 con contatto ausiliario | Apre P1–P3 a valle del driver BLDC prima dello sgancio automatico (D020); il driver BLDC della Core resta | €18 | €18 | 0.2 quadro | TO DESIGN | GenericoSTEP dal fornitore scelto
PP-EL-BOX | Electrical | Quadro DIN + catena E-stop | 1 | DIN cabinet, relè di sicurezza, morsetti | Sostituisce il quadro compatto Core; E-stop e interlock cabina (D025) sul relè di sicurezza | €70 | €70 | 1.8 quadro | TO DESIGN | GenericoSTEP dal fornitore scelto
D · ToolDock automatico
MC-TD-003 | ToolDock | Automatic clamp | 1 | Pull-stud comune (ICD v4) | Pacco molle ≥ 0,5 kN (classe L), sgancio passivo con camma 3:1 (D016); si monta nelle sedi già lavorate della master Core | €60 | €60 | 0.4 macchina | CRITICAL DESIGN | STEP pezzo ↓CAD di dettaglio
MC-TD-004 | ToolDock | Hybrid connector set | 1 | Power + signal + ID, disegno MultiCNC | Sostituisce il connettore circolare manuale Core | €60 | €60 | 0.3 macchina | CRITICAL DESIGN | GenericoSTEP dal fornitore scelto
MC-TD-007 | ToolDock | Connettore dati | 1 | Blind-mate schermato, 18 contatti + schermo | Ethernet 1000BASE-T + CAN FD + encoder RS-422 (ICD v4, profilo Platform) | €45 | €45 | 0.1 macchina | TO SOURCE | GenericoSTEP dal fornitore scelto
E · Cablaggio e metrologia
PP-CAB-001 | Electrical | Cavi dati e ibrido macchina–quadro | 1 set | Cablaggi preassemblati schermati | Si affiancano ai cavi Core, che restano (motori con poli encoder già previsti) | €35 | €35 | 0.5 macchina | TO SOURCE | GenericoSTEP dal fornitore scelto
MC-PROBE-001 | Metrology | XYZ touch probe | 1 | Wired probe class | Work offset / edge finding; incluso nel pacchetto | €30 | €30 | 0.2 macchina | TO QUALIFY | GenericoSTEP dal fornitore scelto
F · Accessori (non inclusi nei totali)
MC-TD-006 | ToolDock | Magazine indicizzato | 1 | 2–4 posti, indicizzazione motorizzata | Sul ponte; richiede il Platform Pack (D016, D021) | €200 | €200 | 2.0 accessorio | TO DESIGN | STEP pezzo ↓CAD di dettaglio
G · Totali provvisori
Stima ingegneristica attuale (target cost a lotto 50, non RFQ) |  |  |  |  |  |  | €829 | 1.6 + 4.8 | PROVISIONAL
Listino TARGET (D026) |  |  |  |  |  |  | ~€1.490 |  | TARGET

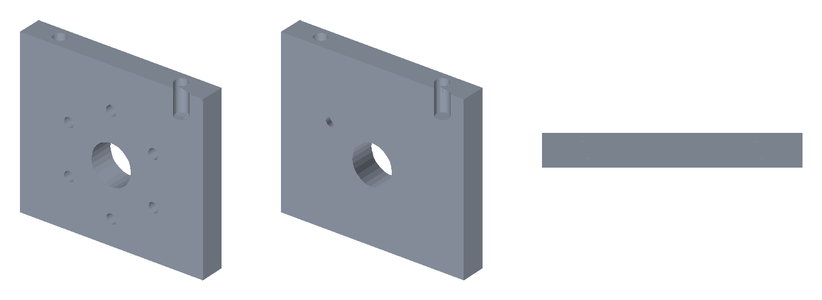
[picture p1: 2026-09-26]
cad/light/parts/views/y_nut_bracket.png

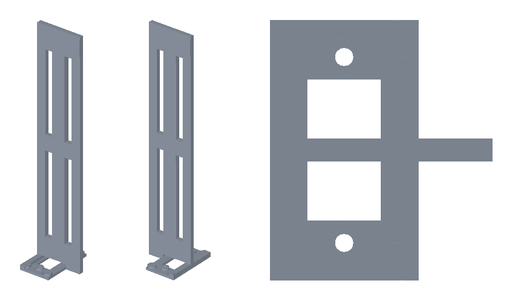
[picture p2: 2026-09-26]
cad/pro/parts/views/upright_L.png

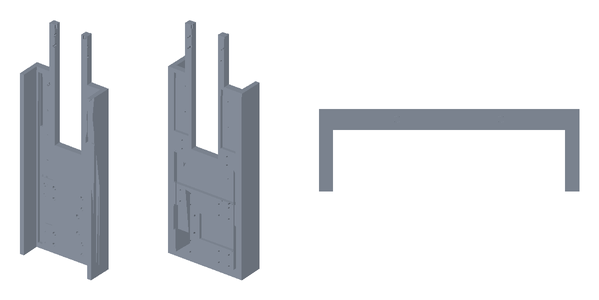
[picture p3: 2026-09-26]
cad/standard/parts/views/x_carriage.png

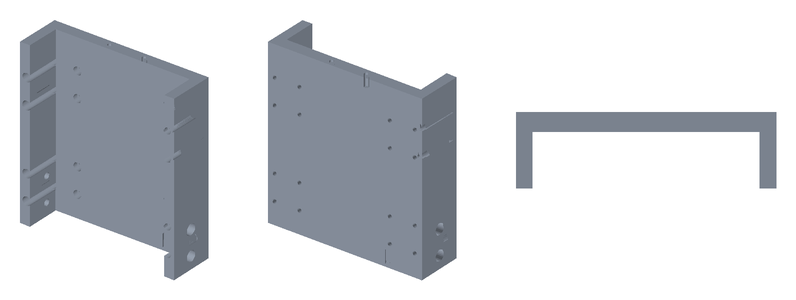
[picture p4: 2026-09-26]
cad/pro/parts/views/z_slide.png

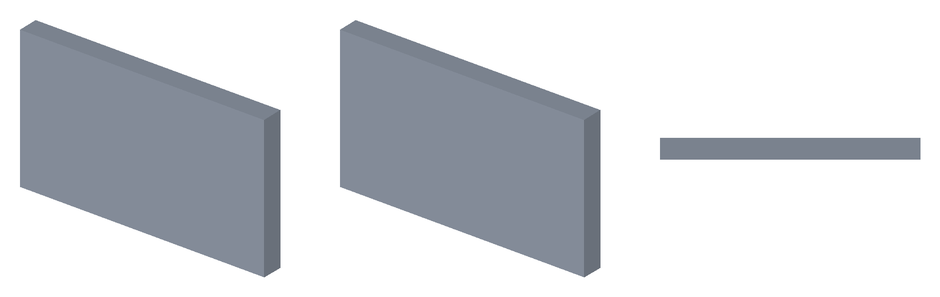
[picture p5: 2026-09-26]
cad/pro/parts/views/lift_bk_bracket_R.png

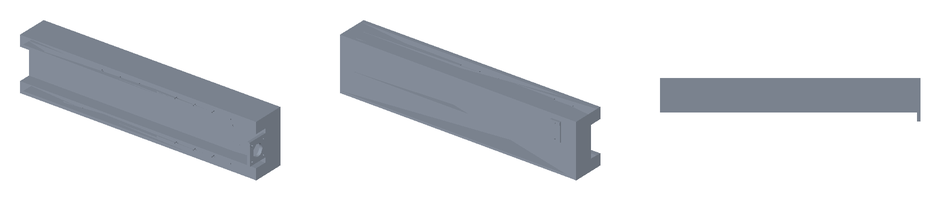
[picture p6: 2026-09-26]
cad/pro/parts/views/beam.png

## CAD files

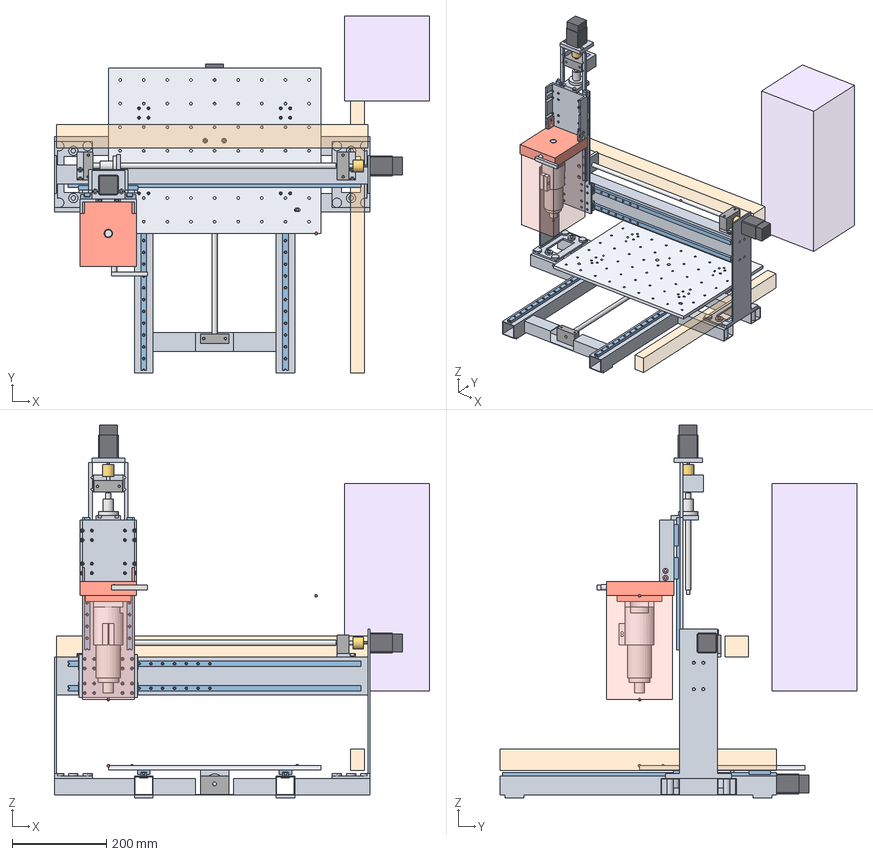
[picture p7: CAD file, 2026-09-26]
cad/light/light_mule_home.step
794.0 x 755.0 x 789.0 mm
frame_longeron_L
frame_longeron_R
frame_cross_bf
frame_cross_rear
frame_cross_end
upright_L
upright_R
beam
x_rail_top
x_rail_bot
x_screw
x_bf
x_bk
x_pads
x_coupling
x_motor
y_rail_L
y_rail_R
y_screw
y_bf
y_bk
y_coupling
y_motor
chain_x_volume
chain_y_volume
magazine_volume
table
y_block_00
y_block_01
y_block_10
y_block_11
y_nut
y_nut_bracket
x_carriage
x_block_00
x_block_01
x_block_10
x_block_11
z_rail_0
z_rail_1
x_nut
x_nut_bracket
z_screw
z_bk
z_coupling
z_motor_bracket
z_motor
z_slide
z_block_00
z_block_01
z_block_10
z_block_11
z_nut_tab
z_nut
tooldock_master
head_receiver
head_mount
head_spindle
head_connector
head_volume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

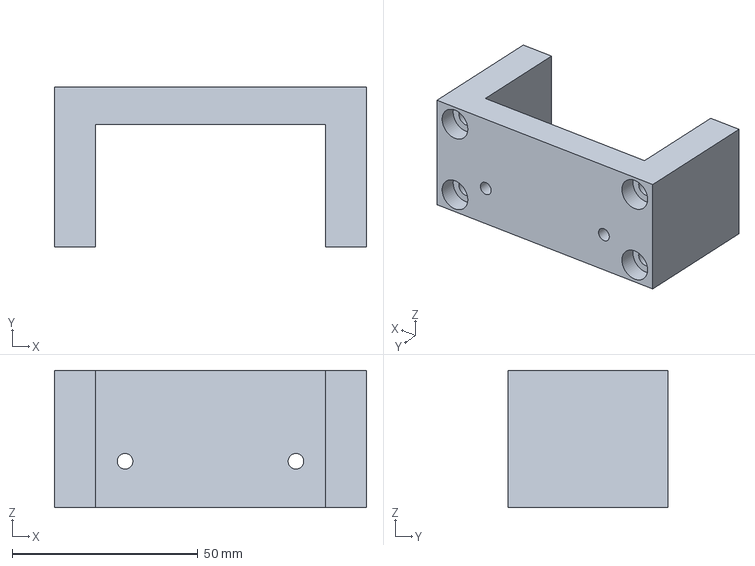
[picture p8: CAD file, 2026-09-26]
cad/light/parts/ML-BRK-001_z_bk_bridge.step
84.0 x 43.0 x 37.0 mm

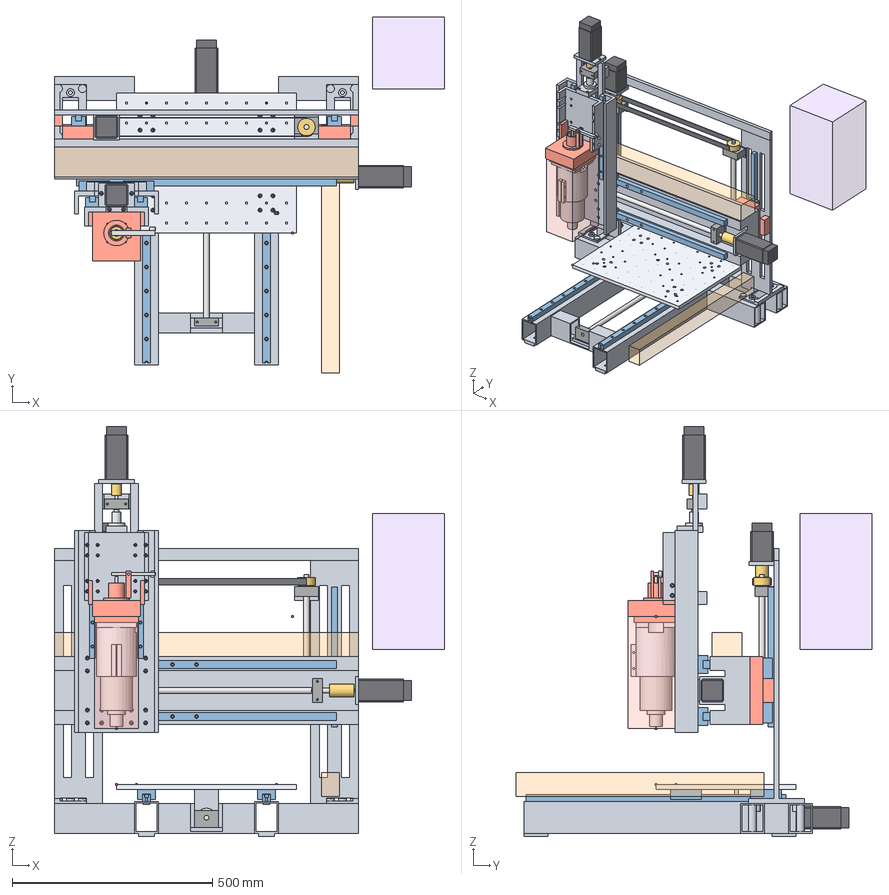
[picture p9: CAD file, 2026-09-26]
cad/pro/pro_mule_home.step
975.0 x 890.0 x 1025.0 mm
frame_longeron_L
frame_longeron_R
frame_cross_bf
frame_cross_rear
frame_cross_bk
frame_cross_end
upright_L
upright_R
beam
x_rail_top
x_rail_bot
x_screw
x_bf
x_bk
x_pads
x_coupling
x_motor
y_rail_L
y_rail_R
y_screw
y_bf
y_bk
y_coupling
y_motor
chain_x_volume
chain_y_volume
magazine_volume
table
y_block_00
y_block_01
y_block_10
y_block_11
y_nut
y_nut_bracket
x_carriage
x_block_00
x_block_01
x_block_10
x_block_11
z_rail_0
z_rail_1
x_nut
x_nut_bracket
z_screw
z_bf
z_bk
z_coupling
z_motor_bracket
z_motor
z_slide
z_block_00
z_block_01
z_block_10
z_block_11
z_nut_tab
z_nut
tooldock_master
head_receiver
head_mount
head_spindle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

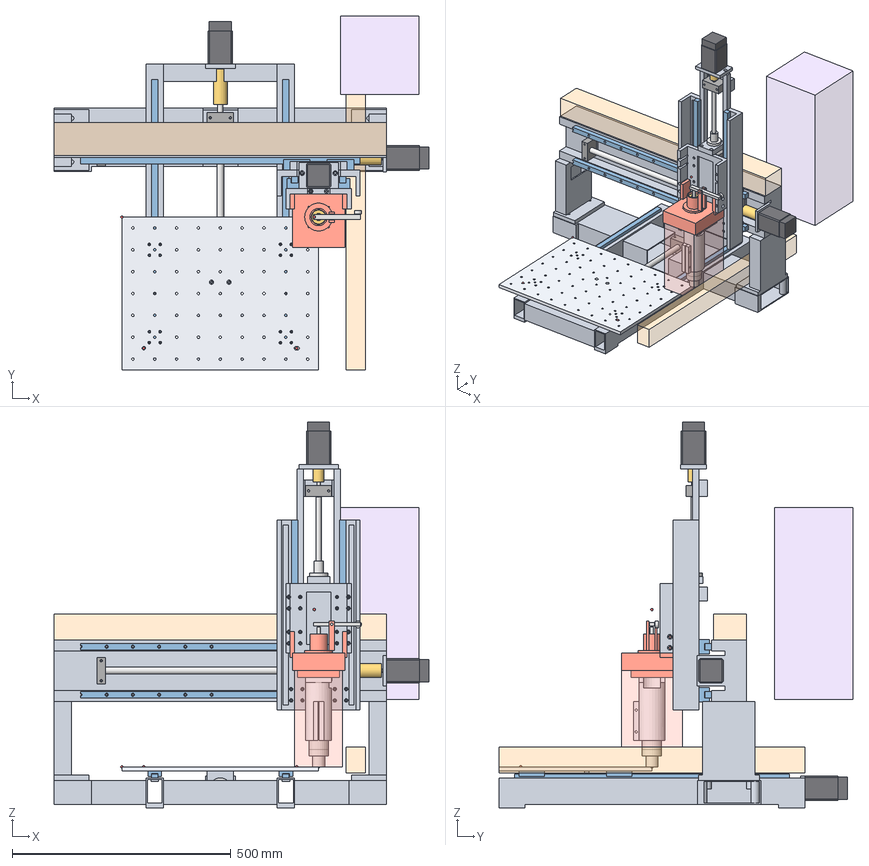
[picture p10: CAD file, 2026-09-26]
cad/standard/standard_mule_max.step
857.0 x 810.0 x 883.0 mm
frame_longeron_L
frame_longeron_R
frame_cross_front
frame_cross_bf
frame_cross_rear
frame_cross_end
upright_L
upright_R
beam
x_rail_top
x_rail_bot
x_screw
x_bf
x_bk
x_pads
x_coupling
x_motor
y_rail_L
y_rail_R
y_screw
y_bf
y_bk
y_coupling
y_motor
chain_x_volume
chain_y_volume
magazine_volume
table
y_block_00
y_block_01
y_block_10
y_block_11
y_nut
y_nut_bracket
x_carriage
x_block_00
x_block_01
x_block_10
x_block_11
z_rail_0
z_rail_1
x_nut
x_nut_bracket
z_screw
z_bf
z_bk
z_coupling
z_motor_bracket
z_motor
z_slide
z_block_00
z_block_01
z_block_10
z_block_11
z_nut_tab
z_nut
tooldock_master
head_receiver
head_mount
head_spindle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

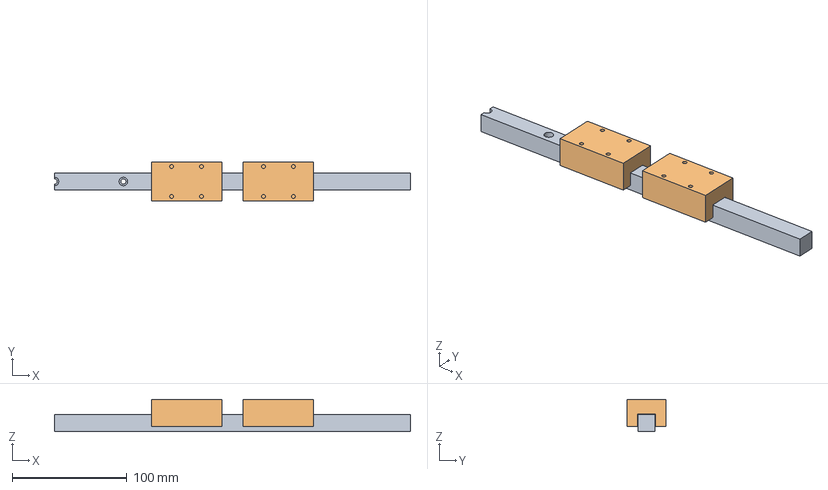
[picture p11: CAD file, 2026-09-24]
cad/step/hgr15_rail_310_2xHGH15CA.step
310.0 x 34.0 x 28.0 mm

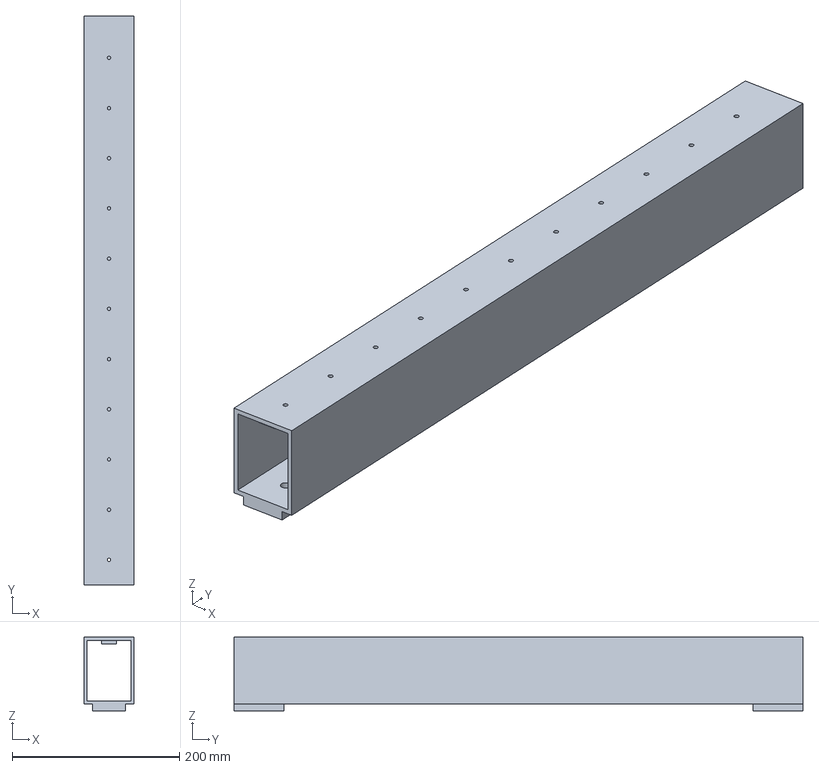
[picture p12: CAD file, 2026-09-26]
cad/pro/parts/MP-BAS-001_frame_longeron_R.step
60.0 x 680.0 x 88.0 mm

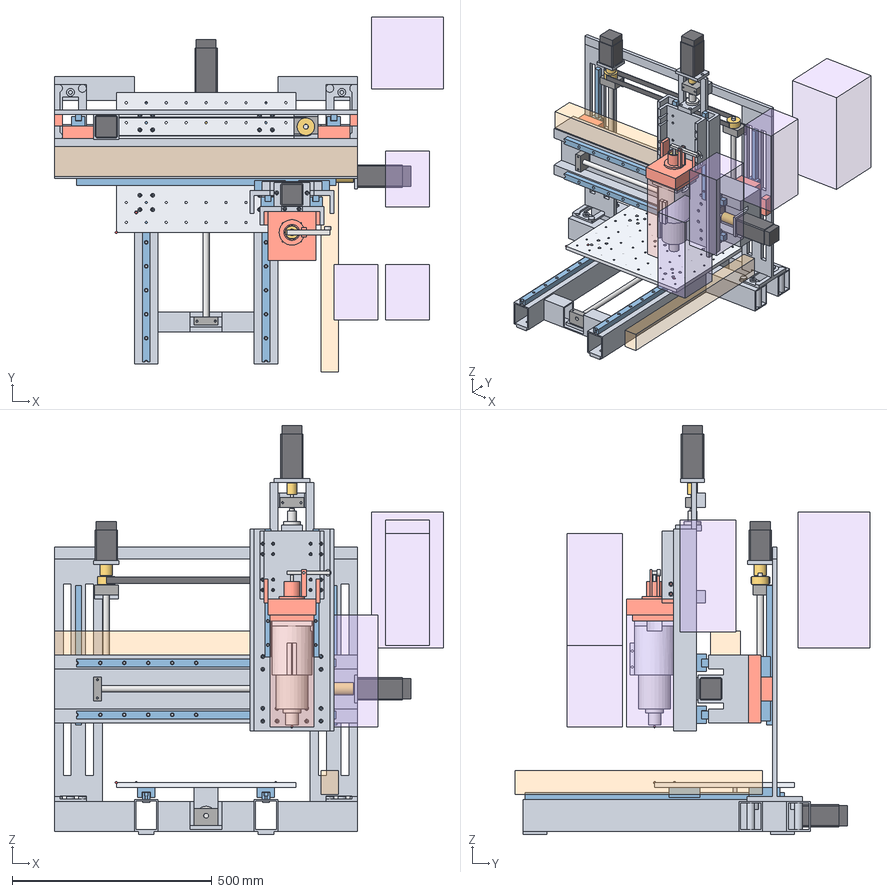
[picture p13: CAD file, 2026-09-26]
cad/pro/pro_mule_dock.step
975.0 x 890.0 x 1025.0 mm
frame_longeron_L
frame_longeron_R
frame_cross_bf
frame_cross_rear
frame_cross_bk
frame_cross_end
upright_L
upright_R
beam
x_rail_top
x_rail_bot
x_screw
x_bf
x_bk
x_pads
x_coupling
x_motor
y_rail_L
y_rail_R
y_screw
y_bf
y_bk
y_coupling
y_motor
chain_x_volume
chain_y_volume
magazine_volume
transfer_head_0
transfer_head_1
transfer_head_2
transfer_head_3
transfer_head_4
table
y_block_00
y_block_01
y_block_10
y_block_11
y_nut
y_nut_bracket
x_carriage
x_block_00
x_block_01
x_block_10
x_block_11
z_rail_0
z_rail_1
x_nut
x_nut_bracket
z_screw
z_bf
z_bk
z_coupling
z_motor_bracket
z_motor
z_slide
z_block_00
z_block_01
z_block_10
z_block_11
z_nut_tab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

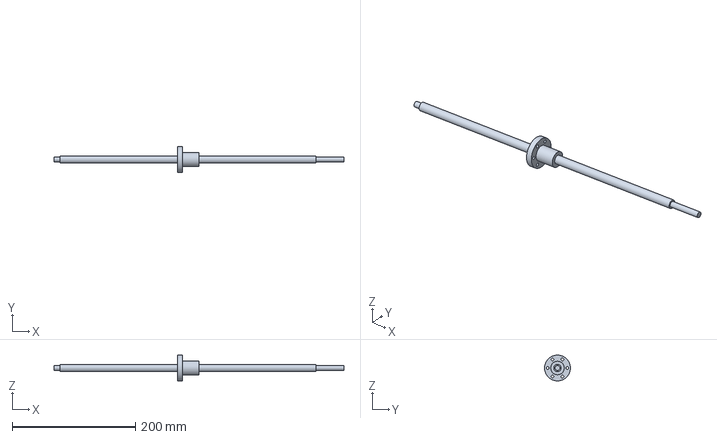
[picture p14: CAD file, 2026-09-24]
cad/step/sfu1204_470.step
470.0 x 42.0 x 42.0 mm

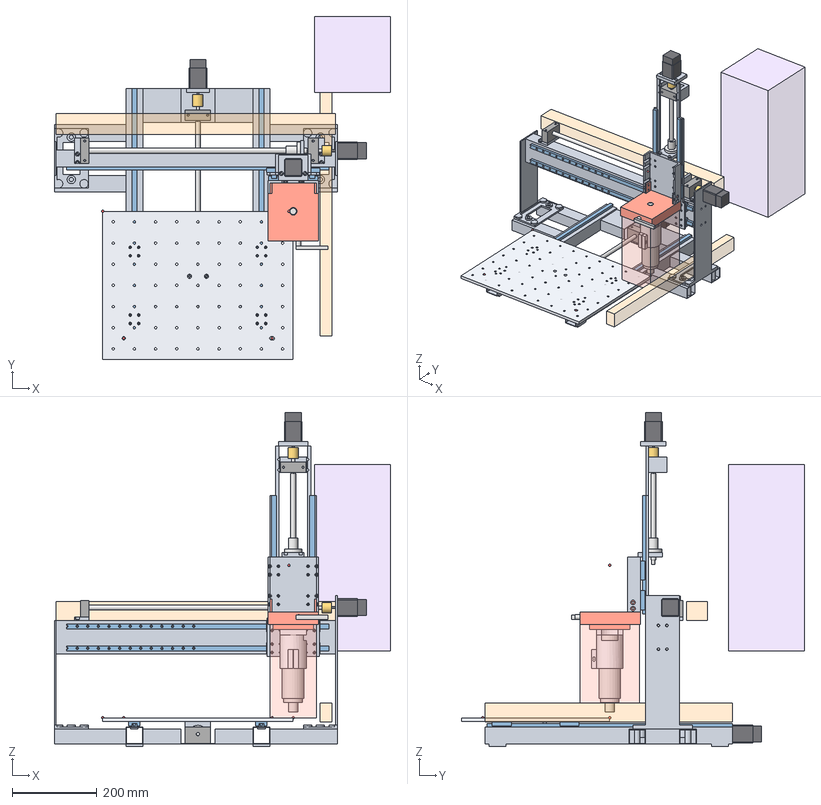
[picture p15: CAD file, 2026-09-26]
cad/light/light_mule_max.step
794.0 x 810.0 x 789.0 mm
frame_longeron_L
frame_longeron_R
frame_cross_bf
frame_cross_rear
frame_cross_end
upright_L
upright_R
beam
x_rail_top
x_rail_bot
x_screw
x_bf
x_bk
x_pads
x_coupling
x_motor
y_rail_L
y_rail_R
y_screw
y_bf
y_bk
y_coupling
y_motor
chain_x_volume
chain_y_volume
magazine_volume
table
y_block_00
y_block_01
y_block_10
y_block_11
y_nut
y_nut_bracket
x_carriage
x_block_00
x_block_01
x_block_10
x_block_11
z_rail_0
z_rail_1
x_nut
x_nut_bracket
z_screw
z_bk
z_coupling
z_motor_bracket
z_motor
z_slide
z_block_00
z_block_01
z_block_10
z_block_11
z_nut_tab
z_nut
tooldock_master
head_receiver
head_mount
head_spindle
head_connector
head_volume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

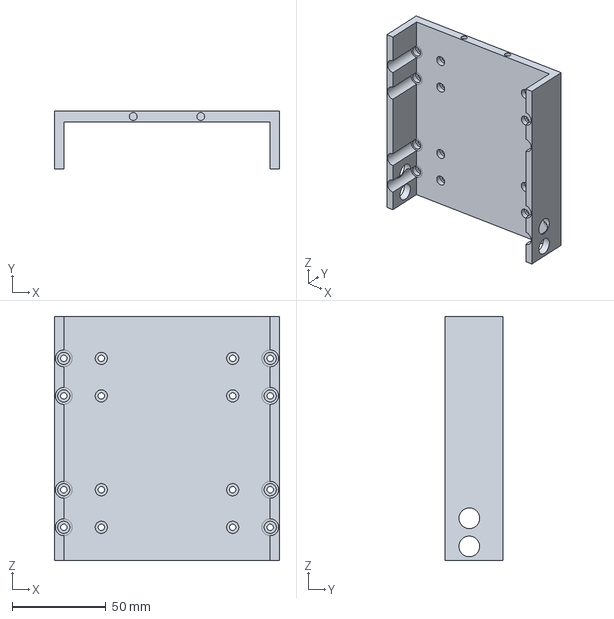
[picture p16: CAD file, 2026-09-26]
cad/light/parts/ML-Z-001.step
120.0 x 31.0 x 130.0 mm

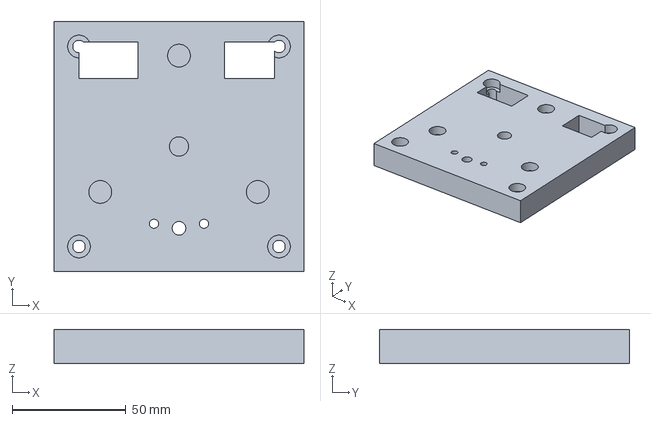
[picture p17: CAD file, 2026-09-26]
cad/pro/parts/MC-TD-002_head_receiver.step
110.0 x 110.0 x 15.0 mm

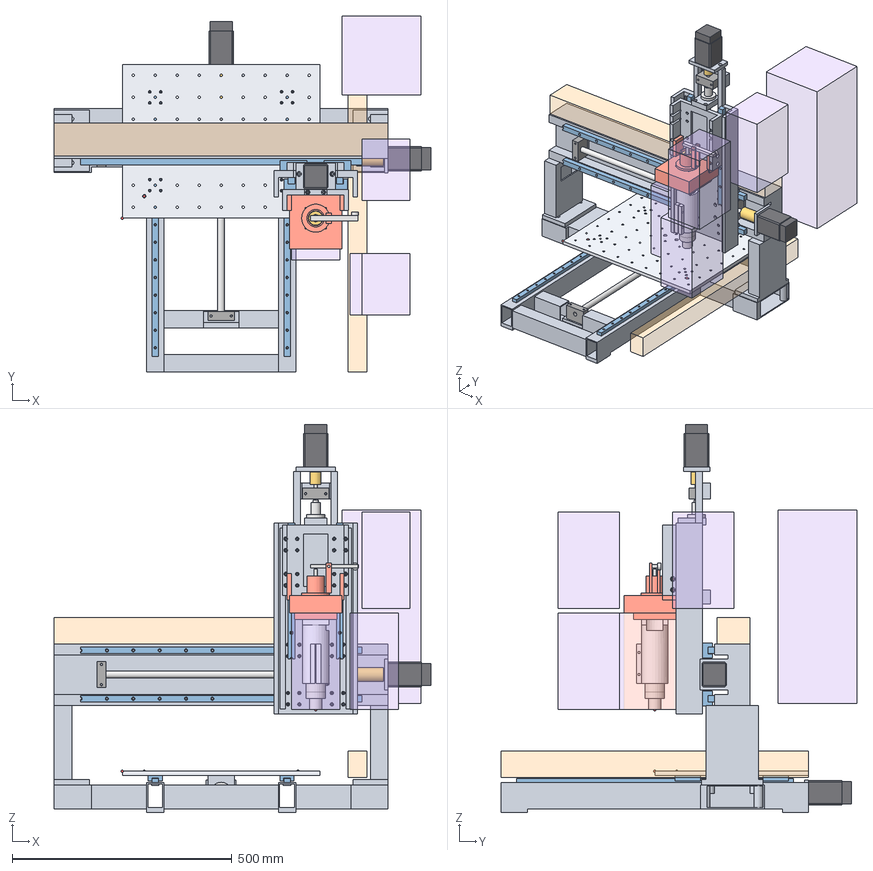
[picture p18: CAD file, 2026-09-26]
cad/standard/standard_mule_dock.step
857.0 x 810.0 x 883.0 mm
frame_longeron_L
frame_longeron_R
frame_cross_front
frame_cross_bf
frame_cross_rear
frame_cross_end
upright_L
upright_R
beam
x_rail_top
x_rail_bot
x_screw
x_bf
x_bk
x_pads
x_coupling
x_motor
y_rail_L
y_rail_R
y_screw
y_bf
y_bk
y_coupling
y_motor
chain_x_volume
chain_y_volume
magazine_volume
transfer_head_0
transfer_head_1
transfer_head_2
transfer_head_3
transfer_head_4
table
y_block_00
y_block_01
y_block_10
y_block_11
y_nut
y_nut_bracket
x_carriage
x_block_00
x_block_01
x_block_10
x_block_11
z_rail_0
z_rail_1
x_nut
x_nut_bracket
z_screw
z_bf
z_bk
z_coupling
z_motor_bracket
z_motor
z_slide
z_block_00
z_block_01
z_block_10
z_block_11
z_nut_tab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

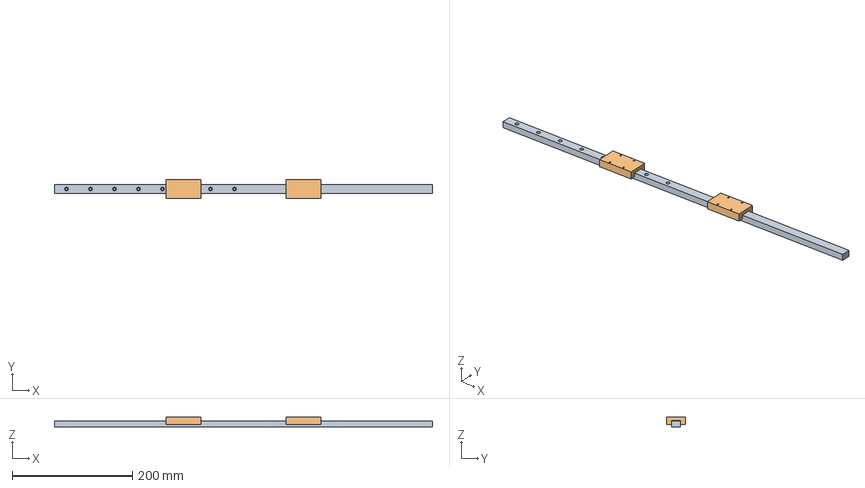
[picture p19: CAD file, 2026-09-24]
cad/step/mgn15_rail_630_2xMGN15H.step
630.0 x 32.0 x 16.0 mm

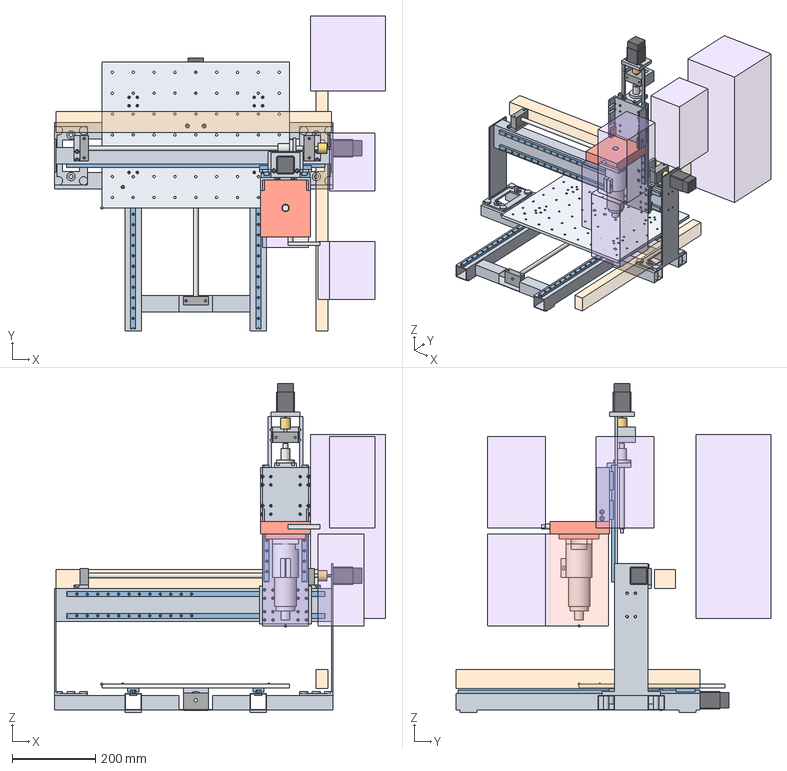
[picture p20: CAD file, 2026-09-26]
cad/light/light_mule_dock.step
794.0 x 755.0 x 789.0 mm
frame_longeron_L
frame_longeron_R
frame_cross_bf
frame_cross_rear
frame_cross_end
upright_L
upright_R
beam
x_rail_top
x_rail_bot
x_screw
x_bf
x_bk
x_pads
x_coupling
x_motor
y_rail_L
y_rail_R
y_screw
y_bf
y_bk
y_coupling
y_motor
chain_x_volume
chain_y_volume
magazine_volume
transfer_head_0
transfer_head_1
transfer_head_2
transfer_head_3
transfer_head_4
table
y_block_00
y_block_01
y_block_10
y_block_11
y_nut
y_nut_bracket
x_carriage
x_block_00
x_block_01
x_block_10
x_block_11
z_rail_0
z_rail_1
x_nut
x_nut_bracket
z_screw
z_bk
z_coupling
z_motor_bracket
z_motor
z_slide
z_block_00
z_block_01
z_block_10
z_block_11
z_nut_tab
z_nut
tooldock_master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

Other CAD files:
cad/light/light_mule_center.step
cad/standard/standard_mule_center.step
cad/pro/pro_mule_max.step
cad/light/parts/ML-GAN-002_upright_L.step
cad/light/parts/MC-ENC-001.step
cad/light/parts/MC-TD-006.step
cad/light/parts/ML-BAS-001.step
cad/light/parts/ML-BAS-001_frame_cross_bf.step
cad/light/parts/ML-BAS-001_frame_cross_end.step
cad/light/parts/ML-BAS-001_frame_cross_rear.step
cad/light/parts/ML-BAS-001_frame_longeron_L.step
cad/light/parts/ML-BAS-001_frame_longeron_R.step
cad/light/parts/ML-BRK-001.step
cad/light/parts/ML-BRK-001_x_nut_bracket.step
cad/light/parts/ML-BRK-001_x_pads.step
cad/light/parts/ML-BRK-001_y_nut_bracket.step
cad/light/parts/ML-BRK-001_z_motor_bracket.step
cad/light/parts/ML-BRK-001_z_nut_tab.step
cad/light/parts/ML-GAN-001.step
cad/light/parts/ML-GAN-001_beam.step
cad/light/parts/ML-GAN-002.step
cad/light/parts/ML-GAN-002_upright_R.step
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

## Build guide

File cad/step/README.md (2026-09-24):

# STEP MultiCNC

Modelli dei componenti commerciali generati da `tools/cad/build_step.py` (CadQuery) a partire da `tools/cad/parts.py`.

- **Quote:** pattini MGN12H, MGN15H, HGH15CA, HGH20CA dalle schede HIWIN (hiwin.de, 2026-09-24); rotaie, viti SFU e motori NEMA closed-loop da quote tipiche di catalogo, da verificare con il fornitore scelto.
- **Uso:** layout, ingombri e assiemi. Per il disegno di dettaglio usare il modello ufficiale del produttore (link nella colonna CAD / STEP delle BOM).
- **Non modificare a mano:** cambiare `parts.py` e rigenerare.
- **Licenza:** modelli propri MultiCNC; licenza di pubblicazione da definire.

`manifest.json` elenca file, dimensione e ingombro (mm) di ogni modello.

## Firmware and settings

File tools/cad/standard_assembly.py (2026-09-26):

#!/usr/bin/env python3
"""Base Standard · "digital mule": assieme parametrico dimensionale.

Brutto ma dimensionalmente corretto. Costruisce l'assieme dai parametri di
standard_params.py e dai componenti commerciali di parts.py (le stesse funzioni che
generano gli STEP in cad/step/: qui rotaie, pattini, viti e chiocciole sono istanziati
separatamente perché nell'assieme si muovono). Per HOME, CENTER e MAX:
- esporta lo STEP dell'assieme (cad/standard/standard_mule_<config>.step);
- controlla collisioni (volume comune) e giochi minimi tra parti in moto relativo;
- calcola bounding box, footprint e massa stimata;
e scrive cad/standard/report.json e la pagina base/cad-standard.html.

Uso (dalla radice, con CadQuery): python tools/cad/standard_assembly.py [--no-step]
"""
import itertools
import json
import math
import pathlib
import sys
import time

HERE = pathlib.Path(__file__).resolve().parent
ROOT = HERE.parents[1]
sys.path.insert(0, str(HERE))
sys.path.insert(0, str(ROOT / "tools" / "bom"))
import cadquery as cq  # noqa: E402
from OCP.BRepExtrema import BRepExtrema_DistShapeShape  # noqa: E402

import base_select  # noqa: E402,F401  (--base light|standard|pro)
import parts  # noqa: E402
import standard_params as P  # noqa: E402

OUT = ROOT / "cad" / P.FILE_PREFIX
D = P.derived()
DETAIL = True          # lavorazioni di dettaglio dei pezzi custom (standard_detail.py); le FEA lo spengono
ORIGIN = (0, 0, 0)

# ---------------------------------------------------------------- primitive


def box(x0, x1, y0, y1, z0, z1):
    return cq.Workplane("XY").box(x1 - x0, y1 - y0, z1 - z0, centered=False).translate((x0, y0, z0))


def cyl(axis, a0, a1, c1, c2, r):
    """Cilindro lungo 'x', 'y' o 'z' da a0 ad a1; (c1, c2) = le altre due coordinate in ordine xyz."""
    w = cq.Workplane("XY").circle(r).extrude(a1 - a0)
    if axis == "z":
        return w.translate((c1, c2, a0))
    if axis == "x":
        return w.rotate(ORIGIN, (0, 1, 0), 90).translate((a0, c1, c2))
    return w.rotate(ORIGIN, (1, 0, 0), -90).translate((c1, a0, c2))


def tube(axis, a0, a1, c1, c2, r_out, r_in):
    return cyl(axis, a0, a1, c1, c2, r_out).cut(cyl(axis, a0 - 1, a1 + 1, c1, c2, r_in))


# orientazioni dei componenti commerciali (locale parts.py: lunghezza X, larghezza Y, altezza Z)
def to_x_on_face(w):          # guida X sulla faccia trave: altezza → −Y, larghezza → Z
    return w.rotate(ORIGIN, (1, 0, 0), 90)


def to_y_on_floor(w):         # guida Y sul basamento: lunghezza → Y
    return w.rotate(ORIGIN, (0, 0, 1), 90)


def to_z_toward_y(w):         # guida Z: lunghezza → Z, altezza → +Y, larghezza → X
    return w.rotate(ORIGIN, (0, 1, 0), -90).rotate(ORIGIN, (0, 0, 1), -90)


def screw_shaft(name, length):
    s, (bk, bf) = parts.SCREWS[name], parts.ENDS[name]
    thread = length - bk - bf
    r_end = s["d"] / 2 - 2
    return (cyl("x", 0, bf, 0, 0, r_end)
            .union(cyl("x", bf, bf + thread, 0, 0, s["d"] / 2))
            .union(cyl("x", bf + thread, length, 0, 0, r_end)))


def screw_nut(name, flange_end=False):
    """Chiocciola lungo +X da 0; flangia sul lato x = 0, o sul lato x = L se flange_end."""
    s = parts.SCREWS[name]
    f0 = s["L"] - s["B"] if flange_end else 0
    body = cyl("x", 0, s["L"], 0, 0, s["D"] / 2).union(cyl("x", f0, f0 + s["B"], 0, 0, s["A"] / 2))
    return body.cut(cyl("x", -1, s["L"] + 1, 0, 0, s["d"] / 2))


def support(kind, x0):
    """Supporto BK/BF lungo X da x0, faccia di montaggio a z = −h, asse a z = 0."""
    q = P.SUPPORTS[kind]
    b = box(x0, x0 + q["T"], -q["W"] / 2, q["W"] / 2, -q["h"], q["H"] - q["h"])
    return b.cut(cyl("x", x0 - 1, x0 + q["T"] + 1, 0, 0, q["bore"] / 2 + 0.1))


def screw_ends(axis_cfg):
    bk, bf = parts.ENDS[axis_cfg["screw"]]
    return bk, bf, axis_cfg["screw_len"] - bk - bf


# ---------------------------------------------------------------- costruzione per gruppo
AL, STEEL = "custom", "commercial"


class Asm:
    def __init__(self):
        self.parts = {}

    def add(self, name, wp, group, kind, bom=None, color="gray"):
        self.parts[name] = dict(shape=wp.val() if hasattr(wp, "val") else wp, group=group,
                                kind=kind, bom=bom, color=color)


def head_box(cx, cy, coupling_z):
    h = P.HEAD
    return box(cx - h["W"] / 2, cx + h["W"] / 2, cy - h["D"] / 2, cy + h["D"] / 2, coupling_z - h["L"], coupling_z)


def transfer_path():
    """Traiettoria del centro testa (x, y, coupling z): magazine → sopra la trave → davanti → giù → lungo −X → dentro lungo +Y (D030)."""
    sx, sy = P.STORE_POSE
    top, dock_z, ya = P.TRANSFER_TOP, D["coupling_top"], P.DOCK_APPROACH_Y
    legs = [((sx, sy, top), (sx, ya, top)), ((sx, ya, top), (sx, ya, dock_z)), ((sx, ya, dock_z), (P.DOCK_X, ya, dock_z)),
            ((P.DOCK_X, ya, dock_z), (P.DOCK_X, 0.0, dock_z))]
    n = P.TRANSFER_STEPS
    lens = [math.dist(p0, p1) for p0, p1 in legs]
    pts = []
    for (p0, p1), ln in zip(legs, lens):
        k = max(2, round(n * ln / sum(lens)))
        pts += [tuple(p0[m] + (p1[m] - p0[m]) * i / k for m in range(3)) for i in range(k)]
    return pts + [legs[-1][1]]


def master_shape(X, cz, wall=None, saddle=True):
    """Master ToolDock scatolata (D029, D030) sotto la slitta Z, dal piano del coupling cz alla faccia inferiore della slitta.
    saddle: guance della sella a U (D031, mule v3) che salgono contro le facce interne delle ali della slitta."""
    M, mw = P.MASTER, (wall if wall is not None else P.MASTER["wall"])
    m = box(X - M["W"] / 2, X + M["W"] / 2, -P.HEAD["D"] / 2, D["slide_back"], cz, cz + M["T"]).cut(
        box(X - M["W"] / 2 + mw, X + M["W"] / 2 - mw, -P.HEAD["D"] / 2 + mw, D["slide_back"] - mw, cz + mw, cz + M["T"] - mw))
    mono = getattr(P, "MONOCOQUE", None)
    if mono:                                   # D032 A1: scatola chiusa con la slitta davanti alla sua faccia anteriore
        w_in = P.PLATE["slide_w"] / 2 - P.SLIDE_FLANGE["t"]
        y0, y1, top, wt = -P.HEAD["D"] / 2, D["slide_front"], cz + M["T"], mono["wall"]
        shell = box(X - w_in, X + w_in, y0, y1, top - 10.0, top + mono["h"]).cut(
            box(X - w_in + wt, X + w_in - wt, y0 + wt, y1 + 1.0, top, top + mono["h"] - wt))
        m = m.union(shell)
    if saddle and getattr(P, "SADDLE", None):
        w_in = P.PLATE["slide_w"] / 2 - P.SLIDE_FLANGE["t"]
        y0, top = D["slide_front"] - P.SLIDE_FLANGE["depth"], cz + M["T"]
        for s in (-1, 1):
            x0, x1 = sorted((X + s * (w_in - P.SADDLE["t"]), X + s * w_in))
            m = m.union(box(x0, x1, y0, D["slide_front"], top - 10.0, top + P.SADDLE["h"]))
    return m


def add_head(a, X, cz, S):
    """Testa reale di riferimento SycoTec 5045 AC-ER11 (D030) appesa sotto il coupling cz: receiver, mount a tazza
    con camicia, spindle e service envelope del connettore / cavo (D031, variante S["connector_mode"])."""
    z_top = cz - S["receiver_t"]
    z_rear = z_top - S["connector"]
    z_h1, z_h0 = z_rear - S["rear"], z_rear - S["rear"] - S["housing"]
    z_neck = z_h0 - S["neck"]
    z_nose = z_neck - S["nose"]
    rw = S["receiver_w"] / 2
    a.add("head_receiver", box(X - rw, X + rw, -rw, rw, z_top, cz), "ZSLIDE", AL, "MC-TD-002", "tomato")
    cb_ = S["clamp_block"] / 2
    zc0 = z_h1 - 10
    # mount a tazza chiusa dal receiver al fondo del collare: collare sul Ø45 h6, cavità per retro e connettore, finestra cavo
    env = P.CONNECTOR_ENVELOPES[S["connector_mode"]]
    win = max(25.0, env["bend_r"] + 10.0)
    mount = box(X - cb_, X + cb_, -cb_, cb_, zc0 - S["clamp_len"], z_top)
    mount = mount.cut(cyl("z", zc0 - S["clamp_len"] - 1, zc0 + 1, X, 0.0, S["d"] / 2 + 0.1))
    mount = mount.cut(cyl("z", zc0, z_top + 1, X, 0.0, S["d"] / 2 + 1.5))
    mount = mount.cut(box(X + 10, X + cb_ + 1, -19, 19, z_top - win, z_top + 1))     # finestra di uscita del cavo verso +x
    a.add("head_mount", mount, "ZSLIDE", AL, "MC-SP-003", "lightgray")
    spindle = (cyl("z", z_h1, z_rear, X, 0.0, 44.8 / 2).union(cyl("z", z_h0, z_h1, X, 0.0, S["d"] / 2))
               .union(cyl("z", z_neck, z_h0, X, 0.0, 44.8 / 2)).union(cyl("z", z_nose, z_neck, X, 0.0, S["nut_d"] / 2)))
    a.add("head_spindle", spindle, "ZSLIDE", STEEL, "MC-SP-001", "silver")
    # service envelope parametrico (D031): non è la geometria del connettore, è lo spazio riservato a spina e cavo
    a.add("head_connector", box(X - 15, X + max(15.0, env["side"]), -18, 18, z_rear, z_top), "ZSLIDE", "volume", None, "black")


def build(X, Y, Zd, cfg=None):
    a = Asm()
    zx, t_top, t_bot = D["zx"], D["table_top"], D["table_bottom"]
    xa, ya, za = P.X_AXIS, P.Y_AXIS, P.Z_AXIS
    L, U, BM, T, C = P.LADDER, P.UPRIGHT, P.BEAM, P.TABLE, P.PLATE
    xcen = P.TRAVEL["X"] / 2
    ytc = T["D"] / 2                    # centro tavola (locale)
    xtc = T["W"] / 2
    top_drive = getattr(P, "X_DRIVE", "face") == "top"      # Light a piastre: vite X sopra la trave, BK/BF sul cielo
    if top_drive:
        y_x_axis = D["beam_face"] + P.X_TOP["dy"]
        zxs = D["beam_top"] + P.X_SCREW_PAD + P.SUPPORTS[xa["bk"]]["h"]
    else:
        y_x_axis = D["beam_face"] + BM["recess_d"] - P.X_SCREW_PAD - P.SUPPORTS[xa["bk"]]["h"]
        zxs = zx
    y_z_axis = D["slide_back"] + P.SUPPORT_GAP_Z + P.SUPPORTS[za["bk"]]["h"]
    z_y_axis = -L["H"] + L["pad_t"] + P.SUPPORTS[ya["bk"]]["h"]      # vite Y fra i longheroni

    # ============ FRAME · telaio a scala (D027) ============
    H, w = L["H"], L["wall"]

    def rtube_y(x0, x1, y0, y1):     # tubo rettangolare con asse lungo Y
        return box(x0, x1, y0, y1, -H, 0).cut(box(x0 + w, x1 - w, y0 - 1, y1 + 1, -H + w, -w))

    dz = L["cross_drop"]                 # traverse ribassate sotto il passaggio dei pattini Y

    def rtube_x(x0, x1, y0, y1):     # tubo rettangolare con asse lungo X
        return box(x0, x1, y0, y1, -H, -dz).cut(box(x0 - 1, x1 + 1, y0 + w, y1 - w, -H + w, -w - dz))
    rails_x = (xtc - ya["rail_spacing"] / 2, xtc + ya["rail_spacing"] / 2)
    lw = L["long_w"]
    for tag, xr in zip("LR", rails_x):
        a.add(f"frame_longeron_{tag}", rtube_y(xr - lw / 2, xr + lw / 2, *L["long_y"]), "FRAME", AL, "MC-BAS-001", "gray")
    inner0, inner1 = rails_x[0] + lw / 2, rails_x[1] - lw / 2
    yc = (D["beam_face"] + D["beam_back"]) / 2
    rear_y = (yc - U["depth"] / 2, yc + U["depth"] / 2)
    mode = P.UPRIGHT_MODE
    FX = (P.BEAM_X[0] - U["t"], P.BEAM_X[1] + U["t"]) if mode == "plate" else P.BEAM_X   # estensione della traversa posteriore
    if mode == "lift":                  # montanti dietro la trave: la traversa posteriore arriva fin sotto la loro flangia
        Lf = P.LIFT
        y_up0 = D["beam_back"] + Lf["bracket_t"] + parts.BLOCKS[Lf["block"]]["H"] + Lf["spacer"]
        yc_up = y_up0 + U["t"] / 2
        rear_y = (D["beam_face"], yc_up + 70.0 + 10.0)
    pw = L["pocket_w"]
    pocket = box(xtc - pw / 2, xtc + pw / 2, -400, 400, -H + w, 1)        # passaggio chiocciola Y fino al fondo del tubo
    if L.get("front_y"):                # Light: niente traversa anteriore (longheroni a sbalzo davanti alla traversa BF)
        a.add("frame_cross_front", rtube_x(inner0, inner1, *L["front_y"]), "FRAME", AL, "MC-BAS-001", "gray")
    sy_th = ya["screw_len"] - sum(parts.ENDS[ya["screw"]])
    bf_pad = (-sy_th / 2 - P.SUPPORTS[ya["bf"]]["T"] - 5, -sy_th / 2)
    bk_pad = (sy_th / 2 + 2, sy_th / 2 + 2 + P.SUPPORTS[ya["bk"]]["T"] + 5)
    a.add("frame_cross_bf", rtube_x(inner0, inner1, *L["bf_y"]).cut(pocket).union(box(xtc - pw / 2, xtc + pw / 2, bf_pad[0], bf_pad[1], -H, -H + L["pad_t"])),
          "FRAME", AL, "MC-BAS-001", "gray")
    ry1 = max(rear_y[1], bk_pad[1] + 5)       # la traversa posteriore arriva sotto il supporto BK Y
    outrig = L.get("rear") == "outrigger"
    if outrig:   # Light: due sbalzi 40 × 40 per lato sotto i bulloni ICD §5 della spalla, traversa BK Y a parte
        rear = None
        for x0, x1 in ((FX[0], rails_x[0] - lw / 2), (rails_x[1] + lw / 2, FX[1])):
            for yy in ((yc_up if mode == "lift" else yc) - 60.0, (yc_up if mode == "lift" else yc) + 60.0):
                o = box(x0, x1, yy - lw / 2, yy + lw / 2, -H, -dz).cut(box(x0 - 1, x1 + 1, yy - lw / 2 + w, yy + lw / 2 - w, -H + w, -w - dz))
                rear = o if rear is None else rear.union(o)
        a.add("frame_cross_rear", rear, "FRAME", AL, "MC-BAS-001", "gray")
    rear = box(FX[0], FX[1], rear_y[0], ry1, -H, -dz).cut(box(FX[0] - 1, FX[1] + 1, rear_y[0] + w, ry1 - w, -H + w, -w - dz))
    for xr in rails_x:   # i longheroni attraversano la traversa posteriore
        rear = rear.cut(box(xr - lw / 2, xr + lw / 2, rear_y[0] - 1, ry1 + 1, -H - 1, 1))
    rear = rear.cut(pocket).union(box(xtc - pw / 2, xtc + pw / 2, rear_y[0], ry1, -H, -H + w)).union(
        box(xtc - pw / 2, xtc + pw / 2, bk_pad[0], bk_pad[1], -H, -H + L["pad_t"]))
    if mode == "lift":                  # la traversa lunga della Pro ingloba la zona della traversa di coda
        rear = rear.cut(box(inner0, inner1, L["end_y"][0], L["end_y"][1], -H - 1, 1))
    if not outrig:
        a.add("frame_cross_rear", rear, "FRAME", AL, "MC-BAS-001", "gray")
    if outrig and L.get("bk_cross"):   # Pro: traversa BK Y a parte, traversa di coda normale
        a.add("frame_cross_bk", rtube_x(inner0, inner1, bk_pad[0] - 5, bk_pad[0] - 5 + lw).cut(pocket)
              .union(box(xtc - pw / 2, xtc + pw / 2, bk_pad[0], bk_pad[1], -H, -H + L["pad_t"])), "FRAME", AL, "MC-BAS-001", "gray")
        end = rtube_x(inner0, inner1, *L["end_y"]).cut(cyl("y", L["end_y"][0] - 1, L["end_y"][1] + 1, xtc, z_y_axis, 20))
    elif outrig:   # Light: traversa di coda 40 × 80 × 40 con il pad del BK Y e la piastra del motore Y
        end = rtube_x(inner0, inner1, bk_pad[0] - 5, L["end_y"][1]).cut(pocket).union(
            box(xtc - pw / 2, xtc + pw / 2, bk_pad[0], bk_pad[1], -H, -H + L["pad_t"]))
    else:
        end = rtube_x(inner0, inner1, *L["end_y"]).cut(cyl("y", L["end_y"][0] - 1, L["end_y"][1] + 1, xtc, z_y_axis, 20))
    a.add("frame_cross_end", end, "FRAME", AL, "MC-BAS-001", "gray")
    if L.get("bottom_plate"):          # Pro: fondo del basamento (nervato = scala + fondo)
        a.add("frame_bottom", box(rails_x[0] - lw / 2, rails_x[1] + lw / 2, L["long_y"][0], L["long_y"][1], -H - L["bottom_plate"], -H),
              "FRAME", AL, "MC-BAS-001", "gray")

    if mode == "box":                   # Standard: spalle scatolate sotto le estremità della trave
        for side, (x0, x1) in (("L", (P.BEAM_X[0], P.BEAM_X[0] + U["t"])), ("R", (P.BEAM_X[1] - U["t"], P.BEAM_X[1]))):
            uw = U["wall"]
            up = box(x0, x1, rear_y[0], rear_y[1], -dz, D["beam_bottom"]).cut(box(x0 + uw, x1 - uw, rear_y[0] + uw, rear_y[1] - uw, -dz + uw, D["beam_bottom"] - uw))
            a.add(f"upright_{side}", up, "FRAME", AL, "MC-GAN-002", "gray")
    elif mode == "plate":               # Light: piastre ai lati della trave, fino al cielo della trave
        mx_ = parts.MOTORS[xa["motor"]]
        for side, (x0, x1) in (("L", (FX[0], P.BEAM_X[0])), ("R", (P.BEAM_X[1], FX[1]))):
            ztop = zxs + mx_[0] / 2 + 8.0 if (top_drive and side == "R") else D["beam_top"]   # la spalla destra porta il motore X
            a.add(f"upright_{side}", box(x0, x1, rear_y[0], rear_y[1], -dz, ztop), "FRAME", AL, "MC-GAN-002", "gray")
    else:                               # Pro: montanti del Gantry Lift dietro le estremità della trave
        top_up = D["beam_top"] + Lf["stroke"] + 90.0
        for side, (x0, x1) in (("L", (P.BEAM_X[0], P.BEAM_X[0] + Lf["plate_w"])), ("R", (P.BEAM_X[1] - Lf["plate_w"], P.BEAM_X[1]))):
            up = box(x0, x1, y_up0, y_up0 + U["t"], -dz, top_up)
            xc_ = (x0 + x1) / 2
            for (u0, u1), (w0, w1) in itertools.product(U.get("windows", ()), U.get("window_x", ())):   # finestre ai lati della guida del lift
                for sg in (-1, 1):
                    up = up.cut(box(min(xc_ + sg * w0, xc_ + sg * w1), max(xc_ + sg * w0, xc_ + sg * w1), y_up0 - 1, y_up0 + U["t"] + 1, u0, u1))
            a.add(f"upright_{side}", up, "FRAME", AL, "MC-GAN-002", "gray")

    bf, bb = D["beam_face"], D["beam_back"]
    bx0, bx1, t = P.BEAM_X[0], P.BEAM_X[1], BM["wall"]
    rh, rd = BM["recess_h"] / 2, BM["recess_d"]
    tf = BM.get("wall_face", t)          # faccia guide X più spessa delle altre pareti (filetto delle viti delle rotaie)
    beam = box(bx0, bx1, bf, bb, D["beam_bottom"], D["beam_top"]).cut(
        box(bx0 + BM["end"], bx1 - BM["end"], bf + tf, bb - t, D["beam_bottom"] + t, D["beam_top"] - t))
    if rd > 0:                           # canale vite sulla faccia guide (Standard, Pro)
        beam = beam.cut(box(bx0 - 1, bx1 + 1, bf - 1, bf + rd, zx - rh, zx + rh))
        beam = (beam.union(box(bx0, bx1, bf + rd, bf + rd + t, zx - rh - t, zx + rh + t))
                .union(box(bx0, bx1, bf, bf + rd + t, zx + rh, zx + rh + t))
                .union(box(bx0, bx1, bf, bf + rd + t, zx - rh - t, zx - rh)))
    a.add("beam", beam, "FRAME", AL, "MC-GAN-001", "gray")

    x_rail0 = xcen - xa["rail_len"] / 2
    for tag, dz in (("top", xa["rail_spacing"] / 2), ("bot", -xa["rail_spacing"] / 2)):
        a.add(f"x_rail_{tag}", to_x_on_face(parts.rail(xa["rail"], xa["rail_len"])).translate((x_rail0, bf, zx + dz)),
              "FRAME", STEEL, "MC-LIN-151", "steelblue")

    bkx, bfx, thx = screw_ends(xa)
    sx0 = xcen - thx / 2 - bfx
    a.add("x_screw", screw_shaft(xa["screw"], xa["screw_len"]).translate((sx0, y_x_axis, zxs)), "FRAME", STEEL, "MC-BS-1605X", "silver")
    rot_face = (lambda wp: wp) if top_drive else (lambda wp: wp.rotate(ORIGIN, (1, 0, 0), 90))  # noqa: E731  normale di montaggio → −Z / −Y
    a.add("x_bf", rot_face(support(xa["bf"], sx0 + bfx - P.SUPPORTS[xa["bf"]]["T"])).translate((0, y_x_axis, zxs)), "FRAME", STEEL, "MC-BKBF-001", "dimgray")
    a.add("x_bk", rot_face(support(xa["bk"], sx0 + bfx + thx + 2)).translate((0, y_x_axis, zxs)), "FRAME", STEEL, "MC-BKBF-001", "dimgray")
    if top_drive:                    # spessori sul cielo della trave, larghi quanto i supporti (60) a sbalzo sul retro
        qy = P.SUPPORTS[xa["bk"]]["W"] / 2
        zt = D["beam_top"]
        ex = 14.0                     # 14 mm oltre il supporto, verso l'esterno: 2 × M5 spessore → trave
        a.add("x_pads", box(sx0 - 10 - ex, sx0 + bfx, y_x_axis - qy, y_x_axis + qy, zt, zt + P.X_SCREW_PAD)
              .union(box(sx0 + bfx + thx + 2, sx0 + bfx + thx + 27 + ex, y_x_axis - qy, y_x_axis + qy, zt, zt + P.X_SCREW_PAD)),
              "FRAME", AL, "MC-BRK-001", "gray")
    else:
        a.add("x_pads", box(sx0 - 10, sx0 + bfx, bf + rd - P.X_SCREW_PAD, bf + rd, zx - 30, zx + 30)
              .union(box(sx0 + bfx + thx + 2, sx0 + bfx + thx + 27, bf + rd - P.X_SCREW_PAD, bf + rd, zx - 30, zx + 30)),
              "FRAME", AL, "MC-BRK-001", "gray")
    mx = parts.MOTORS[xa["motor"]]
    cplx = P.COUPLING[xa["screw"]]
    mfx = FX[1] if mode == "plate" else bx1     # Light: motore X sulla faccia esterna della spalla destra
    a.add("x_coupling", tube("x", sx0 + xa["screw_len"] - 10, mfx - mx[8] + 10, y_x_axis, zxs, cplx["D"] / 2, parts.SCREWS[xa["screw"]]["d"] / 2 - 2 + 0.3),
          "FRAME", STEEL, "MC-CPL-001", "gold")
    if mode != "plate":
        hy, hz, rp = (32.0, 35.0, 20.0) if mx[0] > 50 else (mx[0] / 2 + 4, mx[0] / 2 + 4, mx[3] / 2 + 1)   # NEMA23: quote del mule v3
        a.add("x_motor_plate", box(bx1 - BM["end"], bx1, y_x_axis - hy, bf + rd, zx - hz, zx + hz).cut(cyl("x", bx1 - 10, bx1 + 1, y_x_axis, zx, rp)),
              "FRAME", AL, "MC-BRK-001", "gray")
    a.add("x_motor", parts.motor(xa["motor"]).rotate(ORIGIN, (0, 1, 0), 90).translate((mfx, y_x_axis, zxs)), "FRAME", STEEL, "MC-MOT-001", "black")

    yr0 = -ya["rail_len"] / 2
    for tag, x in zip("LR", rails_x):
        a.add(f"y_rail_{tag}", to_y_on_floor(parts.rail(ya["rail"], ya["rail_len"])).translate((x, yr0, 0)), "FRAME", STEEL, "MC-LIN-155", "steelblue")
    bky, bfy, thy = screw_ends(ya)
    sy0 = -thy / 2 - bfy
    rot_y = lambda wp: wp.rotate(ORIGIN, (0, 0, 1), 90)  # noqa: E731
    a.add("y_screw", rot_y(screw_shaft(ya["screw"], ya["screw_len"])).translate((xtc, sy0, z_y_axis)), "FRAME", STEEL, "MC-BS-1605Y", "silver")
    a.add("y_bf", rot_y(support(ya["bf"], sy0 + bfy - P.SUPPORTS[ya["bf"]]["T"])).translate((xtc, 0, z_y_axis)), "FRAME", STEEL, "MC-BKBF-001", "dimgray")
    a.add("y_bk", rot_y(support(ya["bk"], sy0 + bfy + thy + 2)).translate((xtc, 0, z_y_axis)), "FRAME", STEEL, "MC-BKBF-001", "dimgray")
    my = parts.MOTORS[ya["motor"]]
    cply = P.COUPLING[ya["screw"]]
    a.add("y_coupling", tube("y", sy0 + ya["screw_len"] - 10, L["end_y"][1] - my[8] + 10, xtc, z_y_axis, cply["D"] / 2, parts.SCREWS[ya["screw"]]["d"] / 2 - 2 + 0.3),
          "FRAME", STEEL, "MC-CPL-001", "gold")
    a.add("y_motor", parts.motor(ya["motor"]).rotate(ORIGIN, (1, 0, 0), -90).translate((xtc, L["end_y"][1], z_y_axis)), "FRAME", STEEL, "MC-MOT-001", "black")

    # riserve di volume permanenti (nessuna davanti alla trave, D027)
    cy0 = (y_x_axis + P.SUPPORTS[xa["bk"]]["W"] / 2 + P.CHAIN_X["inset"]) if top_drive else bf + P.CHAIN_X["inset"]   # dietro i supporti X
    a.add("chain_x_volume", box(bx0, bx1, cy0, cy0 + P.CHAIN_X["w"], D["beam_top"], D["beam_top"] + P.CHAIN_X["h"]), "FRAME", "volume", None, "orange")
    a.add("chain_y_volume", box(P.CHAIN_Y["x0"], P.CHAIN_Y["x1"], *P.CHAIN_Y.get("y", L["long_y"]), P.CHAIN_Y.get("z0", 0.0), P.CHAIN_Y.get("z0", 0.0) + P.CHAIN_Y["h"]), "FRAME", "volume", None, "orange")
    M = P.MAGAZINE
    a.add("magazine_volume", box(*M["x"], *M["y"], *M["z"]), "FRAME", "volume", None, "violet")
    if cfg == "DOCK":   # alcune pose della testa lungo la traiettoria del trasferitore (solo visualizzazione)
        for k, (cx, cy, cz) in enumerate(transfer_path()[::10]):
            a.add(f"transfer_head_{k}", head_box(cx, cy, cz), "TRANSFER", "volume", None, "violet")
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

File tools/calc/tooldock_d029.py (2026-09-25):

#!/usr/bin/env python3
"""D029 · ToolDock / Head Structural Optimisation (studio, ICD v4 resta la baseline).

Campagna parametrica sul modello di cedevolezza D028 (tools/calc/compliance_d028.py):
1. master, slitta Z e carrello X scatolati (proposta D028);
2. testa reale: spindle 0,8 kW ER11 Ø65 × 208 mm raffreddato ad aria al posto dell'inviluppo rigido;
3. offset asse utensile ↔ slitta Z: 35 / 45 / 55 / 70 mm;
4. accoppiamento Ø80 / 1,6 kN (baseline) e varianti Ø90 / 2,4 kN, Ø100 / 3,2 kN;
5. ripartizione separata master strutturale / accoppiamento cinematico;
6. sensibilità ai parametri incerti (pattini, chiocciole, cuscinetti, motore, accoppiamento, spindle);
7. previsioni per il test al banco del solo ToolDock.

La geometria delle varianti vale solo nel modello: la variante scelta va riportata in
standard_params.py e ricontrollata con il CAD (collisioni, sweep, trasferitore).
Uso (con numpy): python tools/calc/tooldock_d029.py
"""
import copy
import json
import math
import pathlib
import sys

HERE = pathlib.Path(__file__).resolve().parent
ROOT = HERE.parents[1]
sys.path.insert(0, str(HERE))
sys.path.insert(0, str(ROOT / "tools" / "cad"))
import compliance_d028 as C  # noqa: E402
import standard_params as P  # noqa: E402

BASE = copy.deepcopy(dict(HEAD=P.HEAD, AXIS=P.HEAD_AXIS_FROM_SLIDE))

# spindle candidato (quote tipiche di mercato, da confermare sul pezzo reale)
SPINDLE = dict(name="0,8 kW ER11 Ø65 × 208 mm, aria", d=65.0, body=208.0, mass=2.2,
               receiver=15.0, clamp_band=40.0, nut=20.0, stickout=0.0, k_bearing=40e3, body_t=5.0, mandrel_d=17.0)
TOOL = dict(d=6.0, stickout=25.0, E=600000.0)          # fresa in metallo duro Ø6 in ER11 (max 7 mm): fuori dal punto di misura D014


def tool_k():
    d, L, E = TOOL["d"], TOOL["stickout"], TOOL["E"]
    return 3 * E * math.pi * d ** 4 / 64 / L ** 3       # N/mm, mensola incastrata sulla pinza
RECEIVER_MASS = 0.6
BOXED = dict(master=C.tube(P.MASTER["W"], 50.0, 8.0), slide=C.tube(150.0, 50.0, 8.0), carriage=C.tube(170.0, 60.0, 6.0))
COUPLINGS = [("Ø80 · 1,6 kN (ICD v4)", 40.0, 1600.0), ("Ø90 · 2,4 kN", 45.0, 2400.0), ("Ø100 · 3,2 kN", 50.0, 3200.0)]


def head_hanging():
    s = SPINDLE
    L = s["receiver"] + s["body"] + s["nut"] + s["stickout"]
    return L, dict(clamp=s["receiver"] + s["clamp_band"], nose=s["receiver"] + s["body"], body_d=s["d"], body_t=s["body_t"],
                   k_bearing=s["k_bearing"], mandrel_d=s["mandrel_d"])


def head_envelope():
    """Testa che sta nell'inviluppo 220 mm: spindle più corto della stessa classe (ipotesi)."""
    s = SPINDLE
    L = 220.0
    return L, dict(clamp=s["receiver"] + s["clamp_band"], nose=L - s["nut"] - s["stickout"], body_d=s["d"], body_t=s["body_t"],
                   k_bearing=s["k_bearing"], mandrel_d=s["mandrel_d"])


def head_through():
    """Testa passante: l'accoppiamento abbraccia il corpo dello spindle a metà altezza."""
    s = SPINDLE
    nose = s["body"] / 2
    L = nose + s["nut"] + s["stickout"]
    return L, dict(clamp=20.0, nose=nose, body_d=s["d"], body_t=s["body_t"], k_bearing=s["k_bearing"], mandrel_d=s["mandrel_d"])


HEADS = {"appesa (reale)": head_hanging, "nell'inviluppo 220": head_envelope, "passante": head_through}


def run(head=None, axis=70.0, coupling=COUPLINGS[0], sec=None, rigid_head_L=None, factors=None):
    """Ritorna la cedevolezza al centro corsa per la variante."""
    P.HEAD = dict(BASE["HEAD"])
    s = dict(sec or {})
    if head is not None:
        L, hd = HEADS[head]()
        P.HEAD["L"] = L
        s["head"] = hd
    elif rigid_head_L:
        P.HEAD["L"] = rigid_head_L
    P.HEAD_AXIS_FROM_SLIDE = axis
    C.D = P.derived()
    _, C.COUPLING_R, C.HERTZ_PRELOAD = coupling
    for k, v in (factors or {}).items():
        setattr(C, k, v)
    L_used = P.HEAD["L"]
    try:
        r = C.compliance(*P.CONFIGS["CENTER"], sec=s)
    finally:
        C.COUPLING_R, C.HERTZ_PRELOAD = 40.0, 1600.0
        for k in (factors or {}):
            setattr(C, k, 1.0)
        P.HEAD, P.HEAD_AXIS_FROM_SLIDE = dict(BASE["HEAD"]), BASE["AXIS"]
        C.D = P.derived()
    r.pop("_mass", None)
    return dict(N_per_um={ax: round(r[ax]["N_per_um"], 2) for ax in "XYZ"},
                share={ax: {k: round(v * 100, 1) for k, v in r[ax]["share"].items()} for ax in "XYZ"},
                L=L_used)


def bench(coupling, L):
    """Test al banco del solo accoppiamento: leva L, carico laterale F, master e receiver rigidi."""
    _, R, Pre = coupling
    C.COUPLING_R, C.HERTZ_PRELOAD = R, Pre
    k, kc = C.coupling_k()
    C.COUPLING_R, C.HERTZ_PRELOAD = 40.0, 1600.0
    per_N = L ** 2 / k[3] + 1 / k[0]            # mm/N
    return dict(k_rot_Nm_per_urad=round(k[3] / 1e9, 3), k_lat_N_per_um=round(k[0] / 1e3, 1), contact_N_per_um=round(kc / 1e3, 1),
                um_at={F: round(F * per_N * 1e3, 1) for F in (50, 100, 150)}, N_per_um=round(1 / (per_N * 1e3), 2))


def cog_below_coupling(head):
    s = SPINDLE
    L, hd = HEADS[head]()
    body_mid = hd["nose"] - s["body"] / 2
    return round((s["mass"] * body_mid + RECEIVER_MASS * s["receiver"] / 2) / (s["mass"] + RECEIVER_MASS), 0)
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

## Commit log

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2026-09-24 Replace placeholder Base BOM with detailed engineering bill of materials
2026-09-24 Fix doc inconsistencies and redesign the documentation UI
    - BOM: line count 38 -> 46, prototype total aligned to subtotal sum (EUR 4,108)
    - Cost target aligned to the BOM V0.4 figure (EUR 2.6-3.0k) across pages
    - Single documentation version V0.4 (README, dashboard, sidebar, overview)
    - nav.js resolves links relative to its own URL: works from file://,
    domain root and GitHub Pages subpaths; absolute href="/" removed
    - Removed legacy top bars; docs/index.html now redirects to the one dashboard
    - New visual system: blueprint grid, Space Grotesk/JetBrains Mono, status
    pills, spotlight cards, animated machine blueprint hero, roadmap progress,
    sidebar search (/), reading progress bar and pr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
2026-09-24 Freeze Y kinematics: fixed gantry, moving Y table (D006)
    Ponte fisso con X e Z sulla trave, asse Y come tavola mobile con una
    sola vite SFU1605 centrale. Aggiornati decision log, architettura
    meccanica, cinematica XYZ, Gantry Lift, master spec, vincoli, BOM e
    dashboard. Prezzi BOM invariati (totale EUR 4,108). Corretto anche
    l'ultimo target di costo EUR 2.2-2.5k rimasto in general/constraints.
    Claude-Session: https://claude.ai/code/session_01AeHu9SfZFRKeSq2v9gF1Af
2026-09-24 D007: three bases (Light / Standard / Pro), one kit system
    - New base/lineup.html: comparison, common platform, ToolDock payload
    (2/4/7 kg) and kit compatibility matrix
    - bom/base.html is now the Standard BOM (40 lines, EUR 3,218) with a
    per-line mass estimate: 37.8 kg mechanics + 7.8 kg external cabinet,
    above the 25-30 kg target, with the identified levers
    - Previous V0.4 BOM kept as bom/base-pro.html (Pro reference)
    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
2026-09-24 D008: MGN15 X/Y and mass levers on the Standard base
    - X/Y guides HGR15 -> MGN15 with MGN15H blocks (Z stays HGR15)
    - Optimized ribbed base, 8 mm pocketed Y table, 0.5-0.8 kW air spindle
    - Risers and dock rail moved to an accessories group excluded from totals
    - Standard BOM: 38 lines, EUR 3,014, 31.0 kg mechanics (was 37.8 kg),
    still ~1 kg above the 25-30 kg target
    - Values propagated to line-up, chapters, requirements and dashboard
    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
2026-09-24 D009 Standard accepted at ~31 kg; add Base Light BOM
    - D009: Standard mass target set to ~31 kg (BOM estimate after D008)
    - New bom/base-light.html: 38 lines, EUR 2,506, 21.5 kg mechanics +
    5.8 kg external cabinet; 10-15 kg target not met, levers and open
    decision documented (area or automatic ToolDock would break D007)
    - Light shares MC- parts with the Standard (ToolDock, controller,
    safety, metrology); ML- parts are Light-specific
    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
2026-09-24 D010: Base Light at ~18 kg, 450x350 and common ToolDock kept
    - MGN12 on all axes, thinner frame and plates, 5 mm pocketed table,
    SFU1204 ball screws kept
    - Light BOM: 38 lines, EUR 2,430, 18.6 kg mechanics (was 21.5 kg)
    - Rejected: 300x200 area and T8 lead screws
    - Line-up, XYZ, requirements, master spec, README and dashboard updated
    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
2026-09-24 Rebuild Base Pro BOM with per-line mass estimates
    - bom/base-pro.html: 47 lines, EUR 4,028, 70.6 kg mechanics + 12.3 kg
    external units (cabinet, VFD, cooling); ~10 kg over the 50-60 kg
    target, levers and open decision documented
    - MP- codes for Pro-specific parts, MC- for parts common to all bases;
    motor kits split motor/driver; dock rail moved to accessories
    - Line-up, requirements, dashboard, nav and CLAUDE.md updated
    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
2026-09-24 D011: Pro mass accepted at ~70 kg
    Mass is partly a feature on the Pro (damping for aluminium); base,
    gantry with lift and table must stay separately shippable subassemblies.
    Levers are re-evaluated at Pro CAD. Target propagated to BOM Pro,
    line-up, master spec, requirements, README and dashboard.
    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
2026-09-24 D012: freeze common interfaces in ICD v1
    - New base/icd.html: ToolDock 3-ball kinematic coupling, spring clamp
    >= 1500 N normally closed with passive dock-actuated release, payload
    classes L/S/P 2/4/7 kg, hybrid connector pin-out and safety rule,
    1-Wire Module ID, pallet grid M6/50 mm with R1/R2 references, upright
    and riser pattern, machine-cabinet connections
    - Repeatability and change time remain TARGET
    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
2026-09-24 D013: common I/O expansion board on all three bases
    ICD v1 needs ~12-14 inputs, above the 11 of the Mesa 7i96S. Add
    MC-CTRL-003 (expansion on the 7i96S expansion port, >= +16 in / +8 out,
    model to be confirmed with Mesa firmware) to the three BOMs:
    Light 39 lines EUR 2,520, Standard 39 lines EUR 3,104, Pro 48 lines
    EUR 4,118. Control chapter, ICD, master spec, requirements, constraints
    and dashboard updated.
    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
2026-09-24 Add BOM generator in tools/bom
    - data_light.py / data_standard.py / data_pro.py hold the BOM rows
    (price and mass per line), build.py regenerates rows, KPIs and the
    prototype total in the three BOM pages; --check verifies without writing
    - Verified idempotent against the current pages
    - Fix Standard BOM group letters (C was skipped, accessories showed as X)
    - CLAUDE.md: BOM tables are generated, run --check before pushing
    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
    [data_light.py, data_pro.py, data_standard.py]
2026-09-24 BOM: add CAD / STEP column with official vendor download links
    - tools/bom/cad_sources.py maps each part to a verified vendor page
    (HIWIN linear guideway CAD portal, StepperOnline, Mean Well LRS-200 /
    LRS-350 / LRS-600 / HDR-60, Mesa), custom parts to 'MultiCNC CAD, in
    arrivo' and the rest to generic
    - Vendor files are linked, not rehosted: their terms forbid republishing
    - PSU candidates pinned to concrete Mean Well models
    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
2026-09-24 Record technical review: fix errors, mark items under revision
    - Fix: master-spec unclosed cell; dashboard drawing showed Gantry Lift
    screws on the Standard, now pinned risers; dashboard timeline order
    - ICD v1: clamp force, passive release on Light, rack capture
    confirmation, dock rail reference, data bus / differential encoder,
    per-base power budget, R1/R2 on the M6 grid and table thickness
    marked IN REVISIONE (D016-D018)
    - Decision log: open decisions D014-D018 and C7 metrology note
    - Kit matrix: Thermoforming and Fiber MOPA -> DA VERIFICARE
    - Standard MGN15 X/Y marked not frozen (D015)
    - BOM costs relabelled as engineering estimate (target cost, not RFQ)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
2026-09-24 D014 design load cases; D015 rail calculation (proposal)
    - New base/loads.html: radial/axial forces, ToolDock moment, payloads,
    accelerations, rapids, feeds, crash load (axis stall thrust), spindle
    duty cycle and tip stiffness targets for Light / Standard / Pro
    - New tools/calc/rails_d015.py and base/rails.html: rigid-carriage model
    of the X carriage with official HIWIN C0 data; required block stiffness
    vs X rail spacing, static safety factors at design and crash load,
    Y-axis check. Proposal: HGR15/HGH15CA on X with rail spacing >= 110 mm,
    MGN15H on Y. Not applied to the BOM until approved
    - Decision log, nav, XYZ, master spec and dashboard updated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
2026-09-24 D015: HGR15/HGH15CA on X (rail spacing >= 110 mm), MGN15H on Y
    Standard BOM: X rails HGR15 + HGH15CA, Y rails MGN15 + MGN15H (mass
    corrected to the HIWIN 0.09 kg), taller ~80x140 beam. 41 lines,
    EUR 3,146, 32.0 kg; Standard target updated to ~32 kg. Pages, decision
    log and dashboard updated.
    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
    [data_standard.py]
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2026-09-24 Own parametric STEP models of commercial parts, linked from the BOMs
    - tools/cad/parts.py (CadQuery): HIWIN rails + blocks (MGN12H, MGN15H,
    HGH15CA, HGH20CA from hiwin.de datasheets; rail dims typical), SFU1204 /
    SFU1605 screws with flange nut, NEMA17/23 closed-loop motors
    - tools/cad/build_step.py exports 16 STEP files + manifest to cad/step/
    - BOM CAD column: 'STEP MultiCNC' download next to the vendor link for
    rails, blocks, screws and motors on all three bases
    - Light: MGN12H mass corrected to the HIWIN 0.05 kg -> 18.9 kg
    - READMEs for cad/step and tools/cad; CLAUDE.md rules for STEP and calcs
    Claude-Session: https://claude.a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
    [hgr15_rail_300_2xHGH15CA.step, hgr15_rail_350_2xHGH15CA.step, hgr15_rail_600_2xHGH15CA.step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]
2026-09-24 Review 2: D019 real axis lengths, D020 module power / GbE / spindle sequence
    - D019 (tools/calc/axes_d019.py): rails must keep both blocks on the rail
    for full travel + 10 mm margins; all rails were short on every base and
    axis (X 620/640/650, Y 620/630/650, Z 280/310/320 mm). Screw length in
    the BOM is now always total length incl. machined ends; screws set to
    the computed minimum. STEP models regenerated (17), screw model fixed
    - D020 / ICD v3: dedicated 48 V MODULE AUX PSU (LRS-150-48 / LRS-350-48,
    120/120/240 W guaranteed), 24 V to HDR-100-24 (46-48 W), 1000BASE-T data
    connector, mandatory VFD-off -> zero speed -> contactor open -> release
    sequence with a spindle output con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
    [hgr15_rail_310_2xHGH15CA.step, hgr15_rail_320_2xHGH15CA.step, hgr15_rail_600_2xHGH15CA.step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]
2026-09-24 D021 ToolDock magazine, D022 Y rails frozen; ICD v3 pinout and 24 V fixes
    - ICD v3 data connector: D5-D6 were assigned twice; now ETH1-ETH8 (GbE),
    CAN-H/CAN-L, ENC A+/A-/B+/B-/Z+/Z-, +5V/GND, shield: 18 contacts +
    shield, with 100 ohm / Cat5e-class qualification requirement
    - HDR-100-24 is ~92 W (24 V x 3.83 A), not 100 W: power_d020.py fixed,
    24 V guaranteed to modules declared 40 W on all bases
    - D022: HIWIN catalog G99TE23-2203 radial stiffness (MGN15H 89/202,
    HGH15CA 196/365/483 N/um): MGN15H Z1 frozen on Y (x4.6 margin on the
    corner case), HGH15CA ZA on X (x4.1)
    - D021: indexed magazine on the gantry with a single docking position
    replaces the +260 mm X dock zone; MC-TD-006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
    [data_light.py, data_pro.py, data_standard.py]
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2026-09-25 CAD v0: Standard digital mule (params, assembly, HOME/CENTER/MAX checks, STEP, report page, views)
    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
    [standard_mule_center.step, standard_mule_home.step, standard_mule_max.step]
2026-09-25 D027 mule v1: low gantry (b 220 mm), Z blocks on short slide, ladder frame, dock X440 with rear magazine; BOM Standard with mule masses, X carriage and brackets
    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
    [standard_mule_center.step, standard_mule_dock.step, standard_mule_home.step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]
2026-09-25 D028: workspace sweep (125 configs), 3-level clearances, real-head transfer path, mass gate/target; structural compliance model v0 with page
    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
    [standard_mule_center.step, standard_mule_dock.step, standard_mule_home.step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]
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2026-09-25 D030: testa corta 5045-style appesa, digital mule Standard v2
    Spindle di riferimento SycoTec 5045 AC-ER11 (golden reference, prezzi OEM TARGET),
    receiver e mount a tazza con camicia, sealing air e camicia sui passanti ICD v4,
    asse a 53 mm dalla slitta, master scatolata, carrello e slitta a canale, spalle
    scatolate. Sweep 125 config senza collisioni, rigidezza D028 0,91/0,79/1,59 N/um,
    BOM Standard 50 righe, EUR 4.039, 44,8 kg (sopra la soglia 42 kg, aperto).
    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
    [standard_mule_center.step, standard_mule_dock.step, standard_mule_home.step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]
2026-09-25 D031: decisioni candidate sulla testa Standard v2, connettore come service envelope
    Asse spindle 53 mm, presentazione del magazine lungo +Y con accoppiamento in Z (D016),
    42 kg hard target con il v2 sovrappeso accettato fino alla FEA, deroga baricentro
    Standard <= 100 mm, ICD v4 invariata. Connettore M23 non piu quota: envelope
    parametrico RIGHT_ANGLE_ASSUMED / AXIAL con confronto testa e rigidezza D028
    (punta sul dado ER11 reale). Piano FEA a solidi D031.
    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
    [standard_mule_center.step, standard_mule_dock.step, standard_mule_home.step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]
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2026-09-25 Mule v3: sella a U e piastrina chiocciola Z 16 mm; mappe FEA quadratiche
    - standard_params/assembly: SADDLE (guance della master sulle ali della slitta) e
    TAB_T 16 mm; sweep 125, trasferitore e service envelope senza collisioni, 44,9 kg
    - FEA fase 2a: sella + piastrina 16 mm 1,08 / 0,90 / 7,17 N/um (rigida: Z 8,71);
    radice della sella <= ~10 MPa al controllo rapido
    - export_results: facce C3D10 a 6 nodi in 4 triangoli per le tensioni, legenda con
    saturazione al 99,5 percentile e tipo di superficie
    - BOM Standard 44,9 kg; D031, pagine e timeline aggiornate
    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
    [standard_mule_center.step, standard_mule_dock.step, standard_mule_home.step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]
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2026-09-25 D031 chiusa, D032 aperta: Standard stiffness architecture v4
    - Gantry: energia di deformazione per gruppo (somma = lavoro del carico 100,0%) e
    split trave / spalle; sensibilita ed energia concordano: in X/Y slitta Z + master,
    ToolDock e carrello, in Z la trave (56% / 53%), non le spalle (10% / 6%)
    - Tabella diagnostica con baseline 6/12 esplicita
    - D032: D014 separato in service / structural / stiffness derivata, concept v4
    entro 42 kg, ICD v4 invariata; D014 in revisione in loads.html; timeline
    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
2026-09-25 D032: carichi di servizio e budget di deformazione provvisori
    - loads.html: SERVICE NOMINAL / SERVICE HIGH / STRUCTURAL PEAK (XY 60/80/150 N,
    Z 100/150/200 N), budget 20 um diviso tra macchina (naso spindle <-> punto di
    lavoro), utensile e fixture; rigidezza macchina DERIVED/PROVISIONAL >= 4 XY /
    7,5 Z minimo, ~6 / ~8 di progetto
    - D032: concept A compact chain, B structural rethink, C ToolDock challenger,
    gate >= 3 XY / >= 4 Z entro 42 kg, matrice di scelta
    - pagine gantry e mule confrontate con i target D032
    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
    [standard_assembly.py]
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2026-09-26 D032-LIM: stiffness envelope; controllo del bilancio energetico nelle FEA
    - base/fea-d032-lim.html (tools/fea/d032_lim.py): su C3c, massa bloccata, moltiplicatore
    di rigidezza in forma chiusa (verificato con FEA E e k x4 entro 0,05%): solo gantry
    Y=3 richiede x7,6, Z=4 e Y=6 impossibili; macchina intera gate x3,8, progetto x7,5
    - d031_gantry: soluzione accettata solo con bilancio energetico entro 2%, altrimenti
    si risolve di nuovo; C3c e A1 rilanciati: Z 2,08 e 2,07 N/um (erano 2,20 e 2,15)
    - C3c: structural reference only, requires ICD v5 packaging resolution; D032 e menu
    Claude-Session: https://claude.ai/code/session_01AeHu9SfZ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
2026-09-26 D033: CAD di dettaglio della Standard (28 pezzi, 11 righe BOM) + accessori
    - tools/cad/standard_detail.py: lavorazioni dai componenti reali (guide, pattini,
    BK/BF, chiocciole, motori, ICD v4 §5, ToolDock con rulli, sfere, pull-stud, clamp
    a sfere con molle a tazza e leva 3:1, porte e connettori, mount con collare),
    piastre ponte BK/BF Z, viteria compilata (~311 elementi)
    - tools/cad/standard_parts.py: STEP per pezzo e per riga BOM in cad/standard/parts,
    viste, manifest letto dalle BOM, pagina base/cad-parts.html
    - tools/cad/standard_accessories.py: rialzi +75 (dettaglio), magazine + trasferitore
    e cabina (layout)
    - assieme, sweep 125 pose e trasferitore senza collisioni; massa 47,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
    [MC-BAS-001.step, MC-BAS-001_frame_cross_bf.step, MC-BAS-001_frame_cross_end.step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]
2026-09-26 D034: Standard sotto 42 kg (41,8) alleggerendo il CAD di dettaglio
    Telaio 3 mm, trave 4 mm con faccia guide 6 e rinforzi BK/BF, spalle 4 mm con
    flangia ICD 12, tasche su carrello X e slitta Z, mount tondo, piedi e pad piu'
    sottili. Assieme, sweep 125 pose e trasferitore senza collisioni. D028 in
    CENTER 0,88 / 0,77 / 1,46 N/um (prima 0,91 / 0,79 / 1,59). BOM Standard 41,8 kg.
    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
    [MC-BAS-001.step, MC-BAS-001_frame_cross_bf.step, MC-BAS-001_frame_cross_end.step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]
2026-09-26 D035: CAD di dettaglio di Light Core e Pro (con Gantry Lift) dalla stessa pipeline
    - tools/cad/base_select.py + light_params.py / pro_params.py: --base light|standard|pro
    per assieme, dettaglio, pezzi, accessori, GLB e viste; Standard invariata
    - spalle a piastra (Light) e montanti del Gantry Lift (Pro: guide HGR15, viti SFU1605,
    cinghia HTD, motore G, bloccaggi); clamp ToolDock manuale a camma (Light)
    - tre basi senza collisioni in 4 configurazioni, sweep 125 pose e trasferitore
    - pagine cad-light/cad-pro e pezzi, vista 3D, menu, BOM Light/Pro con righe carrello
    e staffe e masse dal CAD (Light 25,8 kg, Pro 85,6 kg, Standard 41,7 kg)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
    [MC-BAS-001.step, MC-BAS-001_frame_cross_bf.step, MC-BAS-001_frame_cross_end.step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]
2026-09-26 D036: Light a piastre sotto 18 kg (17,7 kg dal CAD)
    Vite X sopra la trave 40x80 senza canale (BK10/BF10 sul cielo, guide X a 52),
    telaio in tubi 40x40x1,5 con sbalzi sotto le spalle e traversa di coda 40x80,
    vite Z fissa-libera, spalle 4 mm con flangia ICD 10 scaricata, carrello e
    slitta 6 mm. Opzioni con default invariati per Standard e Pro. Sweep 125 pose
    e trasferitore senza collisioni; BOM Light 17,6 kg, EUR 1.032.
    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
    [MC-ENC-001.step, MC-TD-006.step, ML-BAS-001.step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]
2026-09-26 D037: Pro sotto 70 kg (69,6 kg dal CAD)
    Basamento 80x60x4 senza fondo con sbalzi sotto i montanti del lift e
    traversa BK Y, niente traversa anteriore; montanti del lift 12 mm finestrati,
    traversa superiore 12x30; trave pareti 4 e testate 5; carrello e slitta 12 mm;
    staffe del lift a C. Masse di viti e sincronizzazione dal CAD. Sweep 125 pose
    e trasferitore senza collisioni; Standard e Light invariate.
    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
    [MC-TD-001.step, MC-TD-001_tooldock_master.step, MC-TD-002.step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]
